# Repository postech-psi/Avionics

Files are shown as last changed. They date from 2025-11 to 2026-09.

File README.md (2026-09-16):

# PSI Avionics

Flight software and ground station for the POSTECH PSI rocket avionics system.
The flight computer runs on an Arduino Portenta H7. Its M7 core reads the
sensors and controls parachute deployment; the M4 core records flight data to
SD and sends telemetry over XBee.

The ground station brings live telemetry into one view: 3D attitude and flight
path, sensor plots, flight statistics, and sensor status. It records each
connection and replays saved logs for flight review, with offline satellite
maps for use at the launch site.

## Repository layout

```text
flight-computer/
  src/m7/       Flight control and state estimation
  src/m4/       SD logging and XBee telemetry
  src/shared/   Telemetry and inter-core packet definitions
  lib/          Firmware libraries, including the UKF and modified BMP3XX driver
  docs/         IMU configuration
  legacy/       Original single-core firmware
ground-station/
  Groundstation.py         Ground station with map and log replay
  README.md               Ground station setup and operating guide
  fetch_basemap.py         Offline basemap downloader
  logs/                   Recorded flight data
```

## Build the firmware

Install PlatformIO through VS Code or Python, then build both cores from the
repository root:

```bash
python -m pip install platformio
pio run -d flight-computer
```

The project uses ST STM32 19.5.0 and Arduino Mbed 4.5.0. The sensor libraries
are included in the repository. Keep the local BMP3XX driver: the firmware
uses its normal-mode and nonblocking-read functions.

Read the [firmware guide](flight-computer/README.md) before uploading. It covers
wiring, sensor settings, startup calibration, and deployment behavior. Upload
M4 first, then M7:

```bash
pio run -d flight-computer -e portenta_h7_m4 -t upload
pio run -d flight-computer -e portenta_h7_m7 -t upload
```

## Run the ground station

From the repository root:

```bash
cd ground-station
python -m pip install -r requirements.txt
python Groundstation.py
```

Select the XBee serial port and click **CONNECT**. The app uses **115200 baud**
and starts recording automatically. Check the **REC** indicator; recordings
are saved as a telemetry CSV and an event TXT file under `ground-station/logs/`.
**STOP LOG** ends recording, and **START LOG** opens another session.

Use **PLOT CONTROL** to select graphs and **FOLLOW** to keep the flight path
in view. **OPEN LOG** replays a ground station CSV or a flight-computer SD CSV
after disconnecting the serial port. Replay supports pause, speed selection,
and seeking through the flight.

The [ground station guide](ground-station/README.md) explains the displays,
sensor status, recording formats, and replay controls.

The map opens as a grid when no basemap is installed. Download imagery before
going to the launch site:

```bash
python fetch_basemap.py site1  # 고흥만 항공센터
python fetch_basemap.py site2  # POSTECH 풍동동
```

For another location:

```bash
python fetch_basemap.py mysite --lat 34.61 --lon 127.21 --label "예비 발사장"
```

Maps are saved in `basemaps/` and work offline after download. Restart the app
after downloading and select the site from **MAP**. Downloaded maps and the
tile cache are excluded from Git.

## Legacy firmware

The original single-core project is kept in
[`flight-computer/legacy/`](flight-computer/legacy/README.md), with its original
source, libraries, and build configuration. It builds separately from the
current firmware and uses an older telemetry format.

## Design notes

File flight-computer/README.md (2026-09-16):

# PSI 비행 컴퓨터

Arduino Portenta H7용 로켓 비행 펌웨어다. M7은 센서 수집, 상태 추정,
발사·전개·착지 판단과 서보 제어를 담당한다. M4는 M7에서 받은 데이터를
SD카드에 기록하고 XBee로 지상국에 보낸다.

| 코어 | 소스 | 실행 주기 |
|---|---|---|
| M7 | `src/m7/main_m7.cpp` | 비행 루프 100Hz, UKF는 새 기압 샘플마다 약 50Hz |
| M4 | `src/m4/main_m4.cpp` | 수신 데이터 SD 기록, XBee 송신 25Hz |

기존 단일코어 펌웨어는 [`legacy/`](legacy/README.md)에 있다.
현재 프로젝트를 빌드할 때는 포함되지 않는다.

## 하드웨어 연결

| 장치 | 연결 | 펌웨어가 사용하는 설정 |
|---|---|---|
| EBIMU-9DOFV6 | UART PJ_8 / PJ_9 | 230400 baud, 12필드 ASCII, 100Hz |
| NEO-M9N | UART PG_14 / PG_9 | 38400 baud, UBX-NAV-POSLLH, 25Hz |
| BMP390 | Wire2, I2C 주소 `0x76` | 기압 ×8, 온도 오버샘플링 없음, IIR 계수 3, 50Hz |
| 낙하산 서보 | D2 | 0° 개방, 120° 잠금 |
| XBee | Serial1 | 115200 baud, M4에서 사용 |
| microSD | Breakout 보드 SDMMC 슬롯 | M4에서 사용 |

IMU와 GNSS의 출력 설정은 센서에 미리 저장되어 있어야 한다. 비행 펌웨어는
부팅 때 출력 형식을 설정하지 않는다. IMU 설정과 복구 방법은
[IMU 설정 문서](docs/IMU_EBIMU_CONFIG.md)를 참고한다.

기울기 판정은 기수가 위를 향할 때 `cos(roll) × cos(pitch)`가 약 −1인
장착 방향을 전제로 한다. 센서나 서보 장착을 바꾸면 각도와 개방 방향을
다시 확인해야 한다.

## 1. 빌드

이 문서의 명령은 `flight-computer/`에서 실행한다. PlatformIO가 필요하며,
플랫폼과 프레임워크 버전은 `platformio.ini`에 고정되어 있다.

```bash
pio run
```

결과물은 `.pio/build/portenta_h7_m7/firmware.bin`과
`.pio/build/portenta_h7_m4/firmware.bin`이다. 라이브러리는 `lib/`에 포함되어
있다. BMP3XX 드라이버에는 `setupNormalMode()`와 `readNonBlocking()`이
추가되어 있으므로 원본 라이브러리로 교체하면 현재 코드를 빌드할 수 없다.

## 2. 업로드

**M4를 먼저 올리고 M7을 나중에 올린다.** M7의 `RPC.begin()`이 M4를 부팅한다.

```bash
pio run -e portenta_h7_m4 -t upload
pio run -e portenta_h7_m7 -t upload
```

자동 업로드가 포트 오류로 실패하면 RESET 버튼을 두 번 눌러 DFU 모드로
진입한 뒤 `dfu-util`로 업로드할 수 있다. 아래 주소는 현재 보드 설정의
플래시 시작 주소다.

```bash
dfu-util -l
dfu-util -d 0x2341:0x035b -a 0 -s 0x08100000 -D .pio/build/portenta_h7_m4/firmware.bin
dfu-util -d 0x2341:0x035b -a 0 -s 0x08040000:leave -D .pio/build/portenta_h7_m7/firmware.bin
```

부팅 중 서보가 움직인다. 장착된 분리 장치가 작동할 수 있으므로 전원을
넣기 전에 시험 구성을 확인한다.

## 3. 부팅과 캘리브레이션

```bash
pio device monitor -b 115200
```

M7은 RPC 연결과 송신 스레드를 시작한 뒤 센서를 확인한다. 기압계 초기화는
최대 10초 동안 재시도하고, IMU와 GNSS는 2초 동안 수신 상태를 확인한다.
이후 다음 순서로 준비한다.

1. 서보를 잠금 → 개방 → 잠금 순서로 움직인다.
2. IMU가 응답하면 자이로 영점 보정과 위치 초기화를 수행한다. 자이로 보정
   중에는 정지 상태를 유지한다. 이어지는 15초 자기계 보정 구간에는 로그
   안내에 따라 센서를 여러 방향으로 회전한다.
3. 기압계가 응답하면 6초 동안 기준기압을 측정한다. 이때 기체를 정지시킨다.
4. 미션 시계를 시작하고 `PRELAUNCH`로 전환한다.

기준기압은 정상 모드 설정 성공, 유효 샘플 200개 이상, 거부 샘플 20개 이하,
최대·최소 차이 0.5hPa 이하일 때 사용할 수 있다. 실패하면 고도 발사 판단과
속도 전개 경로가 비활성화된다.

RPC 초기화나 송신 스레드 시작에 실패하면 빨간 LED를 점멸하며 부팅을
멈춘다. IMU와 기준기압을 모두 사용할 수 없으면 발사를 감지할 수 없다.
14초 강제 전개 타이머도 발사가 감지된 뒤에만 시작한다.

## 4. 텔레메트리

지상국 실행 방법은 [저장소 README](../README.md#run-the-ground-station)에 있다.
XBee 프레임은 총 92바이트이며, payload는 little-endian이다.

```text
0x7E | state (1 byte) | float32 × 22 | health (1 byte) | 0x0A
```

float 필드 순서는 `time`, `lat`, `lon`, `euler[3]`, `accel[3]`, `gyro[3]`,
`pos[3]`, `altitude`, `pressure`, `kalman[4]`, `gnssAlt`다.
시간은 미션 시작 후 ms, 기압은 hPa, 고도는 m다. `kalman[4]`에는 추정 고도,
수직속도, 예측 정점고도, 회귀 적합도 R²가 들어간다.

상태 바이트는 `0xBA` PRELAUNCH, `0xBB` LAUNCH, `0xBC` DEPLOY,
`0xBD` LANDED다. 지상국은 마지막 상태를 GROUND로 표시한다.
텍스트 로그는 `0xAA` 접두 바이트와 CRLF로 구분한다.

| Health 비트 | 의미 |
|---|---|
| `0x01` | IMU 데이터가 30ms 이내 |
| `0x02` | 기압 데이터가 60ms 이내 |
| `0x04` | IMU가 500ms 내에 응답 |
| `0x08` | 기압계가 500ms 내에 응답 |
| `0x10` | 유효 GNSS 프레임을 1초 내에 수신 |
| `0x20` | 기준기압 품질검사 통과 |
| `0x40` | 속도 전개 경로가 영구 차단되지 않음 |
| `0x80` | 현재 속도 전개 입력을 사용할 수 있음 |

`0x80`은 발사 여부나 5초 전개 잠금을 나타내는 비트가 아니다.
GNSS 응답 비트도 위치 fix를 보장하지 않는다.

## 5. SD 기록

M4는 부팅마다 사용하지 않은 번호를 찾아 `flight_NNN.csv`와
`flight_NNN.txt`를 만든다. CSV에는 수신한 텔레메트리를, TXT에는 센서 초기화,
캘리브레이션과 상태 전환 메시지를 기록한다. 000부터 999까지 모두 사용하면
새 기록을 시작하지 않는다.

CSV의 `time_ms`와 M7 텍스트 로그의 `[ms]`는 같은 미션 시계를 사용한다.
부팅 로그는 미션 시계가 시작되기 전의 시간을 사용하며,
`[ZERO] mission clock start`가 경계를 표시한다. M4 자체 메시지는 `[M4 ms]`로
구분한다.

마지막 `note` 열은 health 비트를 풀어 쓴 값이다. 여러 상태는 `|`로 이어진다.

| Note | 의미 |
|---|---|
| `ok` | 모든 health 비트가 설정됨 |
| `imu_stale`, `baro_stale` | 센서는 응답하지만 데이터가 제어 유효기간을 넘김 |
| `imu_dead`, `baro_dead`, `gnss_dead` | 센서 응답 시간 초과 |
| `no_baro_ref` | 유효한 기준기압 없음 |
| `vz_settle` | 속도 경로는 유지되지만 현재 입력을 사용할 수 없음 |
| `vz_off` | 속도 전개 경로 차단 |

센서가 끊겨도 마지막 측정값은 남아 있을 수 있다. 지상국의 SD 로그 재생은
측정값 존재 여부 대신 이 note를 읽어 상태를 표시한다.

SD 쓰기는 별도 스레드에서 수행하고 200ms 간격으로 flush와 fsync를 시도한다.
쓰기 오류가 연속 세 번 발생하면 기록을 중단하고 XBee로 알린다. 버퍼가 차면
데이터가 유실될 수 있고, 실패한 쓰기를 재시도하는 과정에서 CSV 행이 중복될
수 있다. LANDED 전환 때 출력되는 비행 요약의 drop 카운터와 시간을 함께 확인한다.

## 6. 동작 원리

### 6.1 실행 구조

M7 루프는 GNSS·IMU·기압 수집, UKF 갱신, 센서 상태 갱신, 비행 판단,
텔레메트리 큐 적재 순서로 실행된다. 10ms 마감 시각을 놓치면 지나간 주기를
건너뛴다. RPC 쓰기와 USB 로그 출력은 별도 송신 스레드가 담당한다.

### 6.2 데이터 흐름

UKF는 IMU의 전역 Z축 가속도와 기압고도를 입력으로 사용한다. GNSS 위치와
해수면고도, IMU 적분 위치는 기록·회수용이며 비행 판단에는 사용하지 않는다.
기압고도는 부팅 때 정한 기준기압에 대한 상대 높이다.

### 6.3 센서 입력

IMU는 `*roll,pitch,yaw,gx,gy,gz,ax,ay,az,dx,dy,dz` 형식의 12필드만 받는다.
숫자 형식, 유한값, 자세·각속도·가속도 범위를 확인한 뒤 갱신한다.

기압은 300–1250hPa 범위를 확인한다. 직전 유효 샘플과 200ms 이내라면
고도 변화율도 검사한다. 새 샘플이 없으면 기존 값으로 UKF를 다시 계산하지 않는다.

GNSS는 체크섬이 맞는 UBX-NAV-POSLLH 프레임을 받는다. 수평 정확도가
100m 이내이고 위도·경도 범위가 유효할 때 위치를 갱신한다. POSLLH에는
fix 유효 플래그가 없으므로 이 조건만으로 항법용 위치를 보장할 수는 없다.

### 6.4 데이터 유효기간

제어 입력 유효기간과 센서 응답 시간 초과는 별개다. IMU 30ms, 기압 60ms를
넘은 값은 해당 제어 투표에 사용하지 않는다. 센서 응답 여부는 더 긴
IMU·기압 500ms, GNSS 1000ms 기준으로 판단한다.

### 6.5 상태 추정

UKF의 시간 간격은 0.02초로 고정되어 있다. IMU의 중력 제거 가속도(g)를
m/s²로 바꾸고 중력항을 더해 필터에 넣는다. 출력 수직속도는 위쪽이 양수다.

기압 간격 100개의 평균이 17.5–22.5ms에 들어오면 속도 경로의 주기 조건을
통과한다. 이후에도 50개 간격마다 평균을 확인한다. 35ms보다 긴 공백이나
최근 네 정상 간격의 합이 70–90ms 범위를 벗어나면 속도 입력을 500ms 동안 막는다.

### 6.6 투표 창

발사와 전개는 한 번의 측정으로 판단하지 않는다. 각 조건이 최근 N회 중
몇 회 참이었는지 센다. 모든 투표는 100Hz 루프에서 갱신되므로 루프가
지연되면 실제 판단 시간도 길어진다.

### 6.7 비행 상태 전환

PRELAUNCH에서는 수직 가속도 절댓값이 2g를 넘는 표가 20회 중 12회이거나,
최근 두 기압 샘플의 평균 고도가 10m를 넘는 표가 40회 중 24회이면 LAUNCH로
전환한다. 고도 경로에는 유효한 기준기압이 필요하다.

발사 감지 뒤 **5초 동안 모든 전개 경로를 잠근다.** 잠금이 풀리면 아래
순서로 판단한다. 14초 타이머는 센서 경로와 별도로 평가한다.

| 경로 | 조건 |
|---|---|
| 속도 | 사용 가능한 추정 수직속도가 −7m/s 미만인 표가 12회 중 7회 |
| 기울기 백업 | 속도 경로가 비활성이고 IMU가 유효할 때, `cos(roll) × cos(pitch) > 0.70711`인 표가 25회 중 15회 |
| 강제 타이머 | 발사 감지 후 14초 초과 |

속도 경로가 선택되어 있으면 기울기 표는 쌓이지 않는다. 다만 잠금 해제 후
속도 입력을 **1000ms 연속 사용할 수 없으면** 속도 경로를 영구 차단하여
기울기 백업을 허용한다. 중간에 입력이 사용 가능해지면 이 연속 시간은
초기화된다. 짧은 공백은 복구를 기다리고, 지속적인 저하는 백업으로 넘긴다.

DEPLOY에 들어가면 서보를 먼저 연다. 1초 동안 개방한 뒤 착지하지 않았으면
500ms 잠갔다 다시 여는 동작을 반복한다. 잠금 중 루프가 지연될 경우를 위해
600ms 후 개방하는 타이머도 설정한다.

착지는 자이로 벡터 크기 5dps 이하, 가속도 벡터 크기 0.2g 이하인 정적
상태가 최근 2500회 중 1500회 누적될 때 판단한다. 기준 고도에서 2m를 벗어나면
투표를 초기화한다. LANDED 전환은 서보가 열린 상태에서만 수행한다.

### 6.8 센서 고장 시 동작

비행 중 기압 공백이 200ms를 넘거나 IMU 응답이 끊기면 속도 경로를 영구
차단한다. IMU가 복구되어도 속도 경로는 다시 켜지지 않고 기울기 백업만
사용할 수 있다. IMU도 사용할 수 없으면 강제 타이머만 남는다.

착지 판단에서는 IMU가 응답하지 않으면 움직임이 없는 것으로 취급한다.
기압계까지 끊기면 고도도 고정되므로, 이 경우의 LANDED 표시는 실제 착지를
확인한 결과가 아니다. 서보 재시도 종료 여부를 해석할 때 구분해야 한다.

### 6.9 설정 위치

주기, 임계값, 투표 수와 시간 제한은 `main_m7.cpp`의 `[4] Parameters`에 있다.
서보 각도는 `[2] Sensor Mapping`, 송신 간격은 M4의 `TELEM_DECIMATE`에서 정한다.
현재 값은 4로, 수신 데이터 네 개마다 한 프레임을 XBee로 보낸다.

### 6.10 코어 간 통신

IPC 프레임은 시작 바이트 `0xA5`, 타입, 2바이트 길이, payload, XOR 체크섬으로
구성된다. M4는 체크섬이 맞는 프레임만 처리한다. M7 송신 큐가 차면
비행 루프를 대기시키지 않고 프레임을 버린 뒤 누락 횟수를 기록한다.

### 6.11 유지보수

비행 루프에 RPC·SD·USB 출력을 직접 추가하지 않는다. 센서 수집 경로에도
시간이 제한되지 않은 대기가 들어가지 않도록 확인한다. 강제 전개 타이머는
루프가 실행되는 동안에만 평가된다.

패킷을 바꿀 때는 `src/shared/telemetry_frame.h`와 지상국의 수신 형식을 함께
수정한다. 서보 동작, 센서 설정, 전개 임계값 변경은 실제 장착 상태에서
확인해야 한다. 빌드 성공만으로 장치 동작이나 비행 적합성을 판단하지 않는다.

## 문제 확인

| 증상 또는 로그 | 확인할 항목 |
|---|---|
| 빨간 LED 반복 점멸 | M4 펌웨어와 업로드 순서, RPC 초기화 오류 |
| `IMU ... format invalid` | 12필드 출력 설정과 230400 baud |
| `GNSS no response` | 38400 baud, UART 출력이 UBX-POSLLH인지 확인 |
| `Baro reference quality fail` | 부팅 중 기체 움직임, 압력 변동, 샘플 수 |
| `vz deploy path disabled` | 함께 출력된 차단 사유와 센서 상태 |
| `SD disabled` | 카드 장착·파일시스템·남은 세션 번호 |
| `SD write failed` | 카드 쓰기 오류. 해당 부팅의 SD 기록은 중단됨 |
| `RPC link` 또는 `deadline skips` | 송신 누락과 비행 루프 실행시간 |

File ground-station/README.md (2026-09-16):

# PSI Ground Station

The ground station receives XBee telemetry from the Portenta H7 flight computer.
It shows the rocket's attitude and flight path alongside sensor plots, flight
statistics, and system messages. The same displays can replay recorded flights
without a serial connection.

## Start the app

Run these commands from the repository root:

```bash
cd ground-station
python -m pip install -r requirements.txt
python Groundstation.py
```

Keep the two STL models and `PSI Logo.png` beside the Python script. The 3D
views load these local assets and use OpenGL.

## Connect and record

1. Connect the receiving XBee to the computer over USB.
2. Click **REFRESH**, select its serial port, and click **CONNECT**. The serial
   speed is fixed at 115200 baud.
3. Check the connection status, incoming telemetry, and **REC** indicator.
   Recording starts automatically when the connection opens.
4. Click **DISCONNECT** when finished. This also closes the recording files.

**STOP LOG** closes the current recording while leaving the serial connection
open. **START LOG** opens a new recording. Each session creates two files in
`ground-station/logs/`:

| File | Contents |
|---|---|
| `log_YYYYMMDD_HHMMSS.csv` | Received telemetry, including timestamps and health flags |
| `log_YYYYMMDD_HHMMSS.txt` | Text events and system messages |

The ground station records what arrives over the radio. The flight computer's
SD recording is a separate source and can contain samples missed by the radio
link. Keep both when reviewing a flight.

## Read the display

| Panel | What it shows |
|---|---|
| **3D ATTITUDE** | Rocket orientation from the IMU |
| **3D FLIGHT PATH** | Position history over a grid or a saved satellite map |
| **PLOT CONTROL · REPLAY** | Graph selection, map controls, and log playback |
| **FLIGHT STATS** | Maximum altitude, ascent and descent rates, acceleration, and deployment and ground times |
| **SENSOR HEALTH** | Sensor response, data freshness, reference pressure, and velocity-path status |
| **TELEMETRY / SYSTEM LOG** | Received values and firmware messages |

The available graphs cover acceleration, angular rate, altitude, vertical
velocity, and predicted apogee. Use the checkboxes to choose the graphs and
individual curves. Double-click a graph after manually panning or zooming to
return to its automatic view.

**FOLLOW** fits the camera to the flight path. Moving the camera manually turns
it off; select it again to resume following. **TOP** switches to a north-up
overhead view. The toolbar **RESET** clears the displayed history and statistics
while the connection and recording continue.

Deployment and ground times in **FLIGHT STATS** are measured from the received
LAUNCH transition. If that transition was missed, the panel shows
`no launch ref`. Predicted apogee is the current onboard estimate; the maximum
altitude statistic is the highest received Kalman altitude.

## Sensor status

IMU and barometer status distinguish **FRESH**, **STALE**, and **DEAD**. A sensor
may still respond while its latest measurement is too old for flight control.
GNSS **ALIVE** means the firmware received an accepted position frame; it does
not guarantee a valid navigation fix.

The velocity path shows **USABLE**, **SETTLING**, or **DISABLED**. These describe
the firmware's velocity input, not whether deployment is armed. The
[firmware guide](../flight-computer/README.md#4-텔레메트리) defines the health
bits and timing thresholds.

## Replay a flight

Disconnect the serial port, then click **OPEN LOG** and choose a telemetry file.
Playback starts immediately. Use the pause/play button, select a speed from
1× to 50×, or drag the slider to inspect a particular point in the flight.
Seeking rebuilds the plotted history and flight statistics up to that point.

The reader accepts ground station CSV recordings, flight-computer SD CSV files
such as `flight_000.csv`, and older TXT logs containing telemetry rows. The
current event-only TXT files do not contain frames for replay; open the paired
CSV instead.

For current SD CSV files, sensor status comes from the `note` column. Older
files without encoded health information use a limited estimate based on the
stored values, so their status display is less complete.

## Prepare offline maps

Download maps while internet access is available. From `ground-station/`:

```bash
python fetch_basemap.py site1  # 고흥만 항공센터
python fetch_basemap.py site2  # POSTECH 풍동동
```

For another location, supply a name and coordinates:

```bash
python fetch_basemap.py mysite --lat 34.61 --lon 127.21 --label "예비 발사장"
```

The downloader creates a PNG and matching JSON metadata in `basemaps/`. Keep
each pair together when copying maps to another computer. Restart the ground
station after downloading, then choose the site from **MAP**. The app reads
these files locally during a flight. Without a downloaded map, it shows a grid.

Downloaded maps and `tilecache/` are excluded from Git. Run
`python fetch_basemap.py --help` for coverage and zoom options.

## Common problems

| Symptom | What to check |
|---|---|
| Serial port is missing | USB connection and adapter driver; click **REFRESH** after reconnecting |
| Port cannot be opened | Close other serial monitors using the same port |
| Connected, but no telemetry | XBee pairing, receiver serial settings, and whether both flight-computer cores are running |
| 3D view fails to open | Graphics driver, OpenGL support, and the STL files beside the script |
| Map list is empty | Download a basemap and restart the app |
| Replay finds no telemetry | Open the CSV rather than an event-only TXT file |

The live receiver expects the current dual-core firmware's packet format.
See the [legacy firmware guide](../flight-computer/legacy/README.md) when
working with the archived single-core project.

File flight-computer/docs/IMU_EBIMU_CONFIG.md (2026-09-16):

# EBIMU-9DOFV6 설정

현재 M7 펌웨어는 230400 baud에서 다음 12필드 ASCII 출력을 받는다.

```text
*roll,pitch,yaw,gx,gy,gz,ax,ay,az,dx,dy,dz
```

출력 설정은 IMU에 저장한다. 비행 펌웨어는 부팅 때 이 형식을 다시 설정하지
않으므로 센서를 교체하거나 초기화한 뒤에는 설정을 확인해야 한다.

## 출력과 측정 범위

| 명령 | 설정 |
|---|---|
| `<sof1>` | Euler 자세각, deg |
| `<sog1>` | 각속도 출력, dps |
| `<soa3>` | 중력을 제거한 전역 좌표계 가속도, g |
| `<som0>` | 지자기 출력 끄기 |
| `<sod2>` | 전역 좌표계 적분 위치 출력, m |
| `<sor10>` | 출력 주기 10ms, 100Hz |
| `<sb6>` | UART 230400 baud |
| `<ssa4>` | 가속도 측정 범위 ±16g |
| `<ssg5>` | 각속도 측정 범위 ±2000dps |

설정 후 한 줄에 숫자 12개가 들어오는지 확인한다. 온도 등 다른 필드를
추가하면 현재 파서가 해당 줄을 거부한다.

`soa3`에서는 정지했을 때 가속도 세 축이 모두 0에 가까워야 한다.
발사 판단에 쓰는 Z축 가속도는 중력이 제거된 전역 수직 가속도다.
`sod2`의 적분 위치는 시간이 지나면 오차가 누적되며, 비행 판단에는 쓰지 않는다.

## 설정 명령 보내기

아래 스케치를 M7에 임시로 업로드하면 USB 시리얼 터미널에서 IMU와 직접
통신할 수 있다. 터미널은 115200 baud로 연다. `IMU.begin()`의 속도는
센서에 현재 저장된 속도와 맞아야 한다. IMU 속도를 바꾼 뒤에는 이 값도
바꾸어 다시 업로드한다.

```cpp
#include <Arduino.h>

UART IMU(PJ_8, PJ_9, NC, NC);

void setup() {
    Serial.begin(115200);
    IMU.begin(230400);
}

void loop() {
    while (Serial.available()) IMU.write((uint8_t)Serial.read());
    while (IMU.available()) Serial.write((uint8_t)IMU.read());
}
```

작업이 끝나면 [비행 펌웨어](../README.md#2-업로드)를 다시 업로드한다.

## 확인과 보정

| 명령 | 용도 |
|---|---|
| `<cfg>` | 저장 설정 확인. 확인 후 `>`를 보내 스트림 재개 |
| `<ver>` | 센서 펌웨어 버전 확인 |
| `<posz>` | 누적 속도·거리 초기화 |
| `<cg>` | 정지 상태에서 자이로 보정 |
| `<cmf>` | 센서를 회전하며 자기계 보정, `>`로 종료 |
| `<caf>` | 가속도 정밀 보정 |
| `<lf>` | 공장 초기화. 이후 출력 형식과 통신 속도를 다시 설정해야 함 |

비행 펌웨어의 부팅 절차에도 자이로 보정, 위치 초기화와 자기계 보정이
포함되어 있다. 부팅 로그에 맞춰 정지와 회전 구간을 구분한다.

과거 로그를 해석할 때는 당시 출력 설정도 확인한다. 이전 `som1` 설정의
로그에서는 `pos` 열에 지자기 값(µT)이 저장되었고, 현재 `sod2` 설정에서는
적분 위치(m)가 저장된다.

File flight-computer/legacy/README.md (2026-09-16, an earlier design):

# Legacy firmware

This is the original single-core Portenta H7 firmware from
[commit 6df6d0e](https://github.com/postech-psi/Avionics/tree/6df6d0e4ed5a65a6c21af55266a050eb3e845649).
The source, libraries, and PlatformIO configuration are kept as they were.

Build it from the repository root:

```bash
pio run -d flight-computer/legacy -e portenta_h7_m7
```

This is a separate PlatformIO project. Building `flight-computer/` does not
include the legacy sources or libraries. Its platform dependency remains
unpinned, as in the original configuration.

The current ground station expects a newer telemetry packet. To use the old
firmware with its original receiver, take the ground-station code from the
same commit or the `legacy-single-core-2026-09-17` tag.

The `legacy-pre-migration-2026-09-17` tag preserves the working tree before
the firmware replacement, including newer ground-station files and flight
logs. It is an archive of that working state; the firmware and receiver in
that tag use different packet formats.

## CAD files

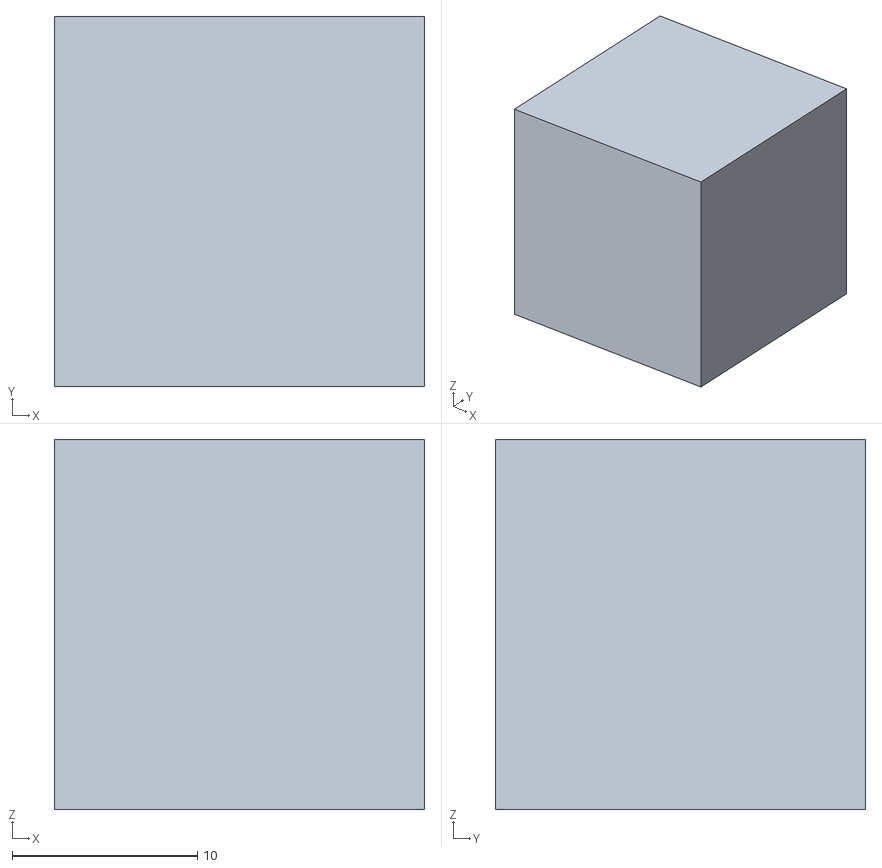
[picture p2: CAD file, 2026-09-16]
ground-station/current_pos_box.stl
20.0 x 20.0 x 20.0

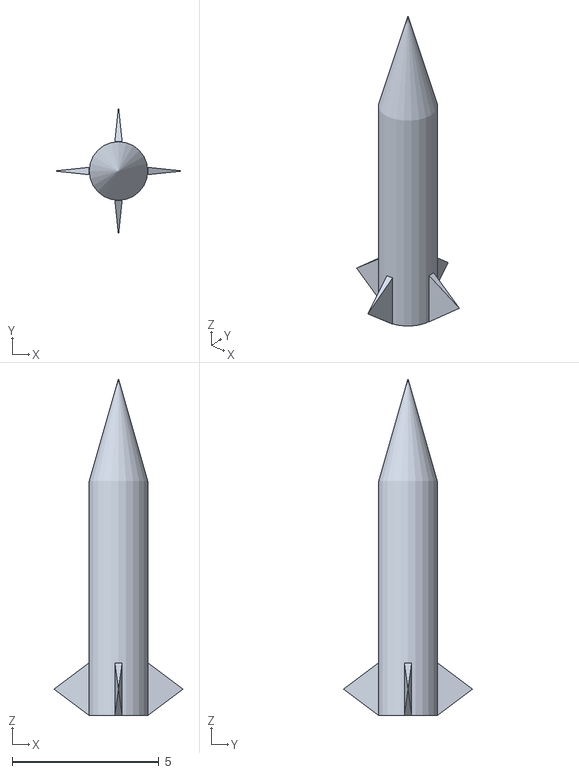
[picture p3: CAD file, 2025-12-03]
ground-station/PSLV_I.V_simplemodel.stl
4.40 x 4.40 x 11.5

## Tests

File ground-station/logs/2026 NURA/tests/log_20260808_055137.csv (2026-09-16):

wall | t | state | lat | lon | gnss_alt | roll | pitch | yaw | ax | ay | az | gx | gy | gz | px | py | pz | baro_alt | pressure | kf_alt | kf_vz | apogee | r2 | health
05:52:28.937 | 0.033 | PRELAUNCH | 36.0213890 | 129.3214417 | 209.42 | 179.310 | 4.350 | -104.020 | 0.0060 | -0.0490 | 0.0100 | -0.710 | 3.520 | -2.520 | -17.177 | -18.079 | -0.652 | -0.063 | 1002.681 | -0.065 | -0.619 | 2.541 | nan | 127
05:52:28.977 | 0.073 | PRELAUNCH | 36.0212364 | 129.3213806 | 102.88 | 179.320 | 4.390 | -104.070 | 0.0040 | -0.0560 | 0.0060 | -0.480 | 4.060 | -0.880 | -17.203 | -18.246 | -0.651 | -0.048 | 1002.680 | -0.054 | -0.066 | nan | nan | 127
05:52:29.020 | 0.112 | PRELAUNCH | 36.0212364 | 129.3213806 | 102.83 | 179.330 | 4.430 | -104.130 | 0.0010 | -0.0600 | 0.0020 | -0.590 | 3.880 | -1.790 | -17.235 | -18.457 | -0.650 | -0.069 | 1002.682 | -0.080 | -0.312 | 0.858 | nan | 127
05:52:29.061 | 0.153 | PRELAUNCH | 36.0212364 | 129.3213806 | 102.74 | 179.340 | 4.440 | -104.180 | -0.0010 | -0.0630 | 0.0000 | -0.410 | 3.450 | -1.180 | -17.260 | -18.627 | -0.649 | -0.074 | 1002.682 | -0.086 | -0.246 | nan | nan | 127
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

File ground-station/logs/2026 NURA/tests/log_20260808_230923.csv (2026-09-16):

wall | t | state | lat | lon | gnss_alt | roll | pitch | yaw | ax | ay | az | gx | gy | gz | px | py | pz | baro_alt | pressure | kf_alt | kf_vz | apogee | r2 | health
23:09:55.487 | 0.033 | PRELAUNCH | 36.0154533 | 129.3218994 | 32.60 | -170.390 | -9.460 | -151.480 | -0.0430 | -0.0540 | 0.0100 | -0.860 | -0.070 | 0.990 | -8.738 | -7.282 | 0.253 | -0.021 | 1006.565 | -0.017 | -0.416 | 1.186 | nan | 127
23:09:55.535 | 0.073 | PRELAUNCH | 36.0154266 | 129.3219452 | 41.22 | -170.330 | -9.590 | -151.480 | -0.0280 | -0.0540 | 0.0180 | 0.000 | 0.000 | 0.000 | -8.772 | -7.322 | 0.256 | 0.003 | 1006.562 | -0.009 | -0.014 | nan | nan | 127
23:09:55.569 | 0.112 | PRELAUNCH | 36.0154228 | 129.3219452 | 41.26 | -170.230 | -9.700 | -151.510 | -0.0280 | -0.0500 | 0.0160 | 0.370 | 0.980 | -0.120 | -8.814 | -7.374 | 0.260 | 0.000 | 1006.563 | 0.013 | 0.223 | nan | nan | 127
23:09:55.623 | 0.153 | PRELAUNCH | 36.0154228 | 129.3219452 | 41.27 | -170.160 | -9.790 | -151.490 | -0.0440 | -0.0470 | 0.0050 | 0.550 | 0.730 | 0.680 | -8.848 | -7.416 | 0.263 | 0.005 | 1006.562 | 0.005 | 0.071 | nan | nan | 127
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

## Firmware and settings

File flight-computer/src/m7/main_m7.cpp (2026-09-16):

//~~~~~~~~~~~~~~~~~~~~~~~~~~~~~~~~~~~~~~~~~~~~~~~~~~~~~~~~~~~~~~~~~~~~~~~~~~~//
//~~~~~~~ main_m7.cpp - Portenta H7 (STM32H747) dual-core avionics : M7 ~~~~~//
//~~~~~~~~~~~~~~~~~~~~~~~~~~~~~~~~~~~~~~~~~~~~~~~~~~~~~~~~~~~~~~~~~~~~~~~~~~~//
// All real-time flight control, single-thread superloop at a fixed 100Hz:
//   GNSS/IMU/Baro -> UKF -> decision FSM -> parachute servo, then the full
//   frame to M4 over RPC. XBEE(Serial1) and SD belong to M4 - never touched here.
//
// EVERYTHING about this file is documented in README section 6:
//   6.1 loop structure   6.3 sensor validity   6.4 freshness grades
//   6.5 UKF at 50Hz      6.6 vote windows      6.7 state transitions
//   6.9 parameter table  6.11 lines you must not delete
// Comments below are limited to "// !" markers on those must-not-delete lines.
// Build & upload (M4 FIRST, then M7) : README 1-2.
//
// [File map] - the [N] tags match the section banners in this file
//   [1] Data Structure      [2] Sensor Mapping     [3] Flight State
//   [4] Parameters          [5] State & Freshness  [6] IPC Transmit
//   [7] Logging             [8] Parsing            [9] Sensor Health
//  [10] VoteWin            [11] Decision          [12] Startup Checks
//  [13] Sensor Check       [14] Setup             [15] Main Loop
//~~~~~~~~~~~~~~~~~~~~~~~~~~~~~~~~~~~~~~~~~~~~~~~~~~~~~~~~~~~~~~~~~~~~~~~~~~~//
#include <Arduino.h>
#include <Servo.h>
#include <Wire.h>
#include <Adafruit_BMP3XX.h>
#include <Adafruit_Sensor.h>
#include "mbed.h"
#include "rtos.h"
#include <chrono>
#include <RPC.h>
#include "ukf.h"
#include "rtwtypes.h"
#include "../parsers.h"
#include "../shared/telemetry_frame.h"
#include "../shared/ipc_protocol.h"

using namespace mbed;
using namespace rtos;
using namespace std::chrono;
kf Kalmanfilter;

//~~~~~~~~~~~~~~~~~~~~~~~~~~~~~~~~~~~~~~~~~~~~~~~~~~~~~~~~~~~~~~~//
//~~~~~~~~~~~~~~~~ [1] Data Structure (M7 local) ~~~~~~~~~~~~~~~~//
//~~~~~~~~~~~~~~~~~~~~~~~~~~~~~~~~~~~~~~~~~~~~~~~~~~~~~~~~~~~~~~~//
struct SensorData {
    uint8_t state = 0xBA;      // 0xBA prelaunch 0xBB launch 0xBC deploy 0xBD landed
    float time = 0.0;          // mission ms
    float lat = 0.0;
    float lon = 0.0;
    float euler[3] = {0, 0, 0};  // roll pitch yaw, deg
    float accel[3] = {0, 0, 0};  // linear accel, gravity-free, GLOBAL frame (soa3), g
    float gyro[3]  = {0, 0, 0};  // dps
    float pos[3]   = {0, 0, 0};  // integrated distance, global, m (drifts - log only)
    float altitude = 0.0;        // above pad reference, m
    float pressure = 0.0;        // hPa
    float kalman[4] = {0, 0, 0, 0};  // kf_alt, kf_vel, apogee, r2
    float gnssAlt = 0.0f;            // GNSS hMSL, m - log/recovery only,
                                     // NEVER used by any flight decision
    uint8_t health = 0;              // TLM_* flags for THIS frame
};

//~~~~~~~~~~~~~~~~~~~~~~~~~~~~~~~~~~~~~~~~~~~~~~~~~~~~~~~~~~~~~~~//
//~~~~~~~ [2] Sensor Mapping (XBEE excluded - owned by M4) ~~~~~~//
//~~~~~~~~~~~~~~~~~~~~~~~~~~~~~~~~~~~~~~~~~~~~~~~~~~~~~~~~~~~~~~~//
Adafruit_BMP3XX Barometer;                    // BMP390, I2C Wire2, 0x76
Servo           Parachute;                    // deploy servo on D2
UART            GNSS(PG_14, PG_9, NC, NC);    // NEO-M9N, UBX-POSLLH, 38400
UART            IMU(PJ_8, PJ_9, NC, NC);      // EBIMU-9DOFV6, 230400

//### Servo geometry (this airframe): 0 deg releases the chute, 120 deg locks ###
const int SERVO_OPEN_DEG  = 0;
const int SERVO_CLOSE_DEG = 120;

//### CLOSE fail-open guard: if the loop dies mid jam-retry, an ISR reopens ###
// ! armed when the retry cycle CLOSES the servo, detached on normal reopen.
//   ISR-safe: after the first write, Servo::write is bounds math + one int32
//   store consumed by the lib's own Ticker (verified in lib/Servo-master).
static mbed::Timeout servoReopenGuard;
static void servoReopenIsr() { Parachute.write(SERVO_OPEN_DEG); }

//~~~~~~~~~~~~~~~~~~~~~~~~~~~~~~~~~~~~~~~~~~~~~~~~~~~~~~~~~~~~~~~//
//~~~~~~~~~~~~~~~~~~~~~~ [3] Flight State ~~~~~~~~~~~~~~~~~~~~~~~//
//~~~~~~~~~~~~~~~~~~~~~~~~~~~~~~~~~~~~~~~~~~~~~~~~~~~~~~~~~~~~~~~//
enum class FlightState { STARTUP, PRELAUNCH, LAUNCH, DEPLOY, LANDED };
FlightState flightState = FlightState::STARTUP;

//~~~~~~~~~~~~~~~~~~~~~~~~~~~~~~~~~~~~~~~~~~~~~~~~~~~~~~~~~~~~~~~//
//~~~~~~~~~~~~~~~ [4] Parameters (README 6.9) ~~~~~~~~~~~~~~~~~~~//
//~~~~~~~~~~~~~~~~~~~~~~~~~~~~~~~~~~~~~~~~~~~~~~~~~~~~~~~~~~~~~~~//
//### Loop & flight thresholds ###
const uint32_t LOOP_PERIOD_MS       = 10;
const float   launchThreshold       = 2;
unsigned long force_deploy_time     = 14000;
const float   fallingspeedThreshold = -7;
const float   TILT_COS_LIMIT        = 0.70711f;
const float   launchAltThreshold    = 10.0f;

//### Vote windows: fire when >= need of the last N votes are true ###
// need = 60% of N (2026-08-04). vz is 7/12 = 58.3% - 12*0.6 = 7.2 is not an
// integer and 7 lands far closer to 60% than 8 (66.7%).
const uint16_t VOTE_ACCEL_N  = 20,   VOTE_ACCEL_NEED  = 12;    // 60%,   ~120ms
const uint16_t VOTE_ALT_N    = 40,   VOTE_ALT_NEED    = 24;    // 60%,   ~240ms
const uint16_t VOTE_VZ_N     = 12,   VOTE_VZ_NEED     = 7;     // 58.3%,  ~70ms
const uint16_t VOTE_TILT_N   = 25,   VOTE_TILT_NEED   = 15;    // 60%,   ~150ms
const uint16_t VOTE_STATIC_N = 2500, VOTE_STATIC_NEED = 1500;  // 60%,    ~15s
const uint32_t DEPLOY_LOCKOUT_MS    = 5000;   // launch+5s: ALL deploy paths locked

//### Static landing (the only landing path) ###
const float    STATIC_GYRO_DPS      = 5.0f;
const float    STATIC_ACCEL_G       = 0.2f;
const float    STATIC_ALT_BAND_M    = 2.0f;

//### Barometer plausibility ###
const float    BARO_MAX_RATE_MPS = 680.0f;    // ~Mach 2 = 13.6m per 20ms sample
const uint32_t BARO_RATE_GAP_MS  = 200;
const uint32_t BARO_STEP_MAX_MS  = 35;        // 10ms polling x 50Hz -> 10/20/30 normal

//### Sensor health timeouts (death/recovery reporting, cal skip) ###
const uint32_t IMU_TIMEOUT_MS    = 500;
const uint32_t BARO_TIMEOUT_MS   = 500;
const uint32_t GNSS_TIMEOUT_MS   = 1000;   // 25Hz UBX stream: 25 missing = dead
const uint32_t HEALTH_LOG_MIN_MS = 2000;
const float    GNSS_HACC_MAX_M   = 100.0f;
const uint32_t BARO_BOOT_SETTLE_MS         = 3000;
const uint32_t BARO_BOOT_RETRY_WINDOW_MS   = 10000;
const uint32_t BARO_BOOT_RETRY_INTERVAL_MS = 1000;
// GNSS_HACC_MAX : POSLLH has no fix flag - a no-fix frame reads lat=lon=0 with
//                 hAcc ~4.29e6 m, so coordinates are taken only when the
//                 reported horizontal accuracy is recovery-grade (measured
//                 module config 2026-08-04). Log/recovery only, gates nothing.

//### Control freshness - SEPARATE from health, gates votes and the UKF ###
const uint32_t IMU_CTRL_FRESH_MS  = 30;
const uint32_t BARO_CTRL_FRESH_MS = 60;
const uint32_t VZ_BARO_GAP_MS     = 200;
const uint32_t VZ_SETTLE_MS       = 500;
// After the deploy lockout, sustained unusability must release the tilt backup.
// Two settle periods allow an isolated short gap to recover without a latch.
const uint32_t VZ_UNUSABLE_TIMEOUT_MS = 1000;
const float    VZ_PLAUSIBLE_MAX   = 200.0f; // |vz| beyond this = filter divergence
const uint16_t CADENCE_ARM_N       = 100;   // clean intervals to arm the vz path
const uint16_t CADENCE_BLOCK_N     = 50;    // rolling re-check block size
const float    CADENCE_MEAN_LO_MS  = 17.5f; // accepted mean band (= rolling-4
const float    CADENCE_MEAN_HI_MS  = 22.5f; //   sum 70..90). Bench: real BMP390
                                            //   ODR measured 19.42ms (+3% fast,
                                            //   oscillator tolerance) - a tight
                                            //   19.5..20.5 band killed vz on a
                                            //   HEALTHY sensor. +-12.5% scale
                                            //   error on vz is harmless; the
                                            //   guard targets 25%+ (25/30ms).
const uint32_t CADENCE_DEADLINE_MS = 10000; // arming give-up (mission ms)
const uint32_t CADENCE_FAST_SUM_LO = 70;    // last-4 clean intervals: sum 70~90
const uint32_t CADENCE_FAST_SUM_HI = 90;    //  = mean 17.5~22.5ms, checked per sample

//~~~~~~~~~~~~~~~~~~~~~~~~~~~~~~~~~~~~~~~~~~~~~~~~~~~~~~~~~~~~~~~//
//~~~~~~~~~~~~~~~~ [5] State Variables & Freshness ~~~~~~~~~~~~~~//
//~~~~~~~~~~~~~~~~~~~~~~~~~~~~~~~~~~~~~~~~~~~~~~~~~~~~~~~~~~~~~~~//
uint32_t Setup_Time    = 0;
uint32_t Setup_Time_us = 0;
float    basePressure  = 1013.0f;
float    altLaunchAvg  = 0.0f;   // mean of the 2 latest REAL baro samples
bool     baroRefValid  = false;  // ground reference passed the quality gate
bool     vzTrusted     = true;   // kalman-vz deploy path enable (one-way latch)
bool     vzCadenceOK   = false;  // measured baro interval matches the UKF's 20ms
uint32_t vzBlockUntil  = 0;      // short-gap blanking deadline
bool     altVotePendingReset = false;  // pre-launch baro gap -> wipe altitude votes
bool     vzVotePendingReset  = false;  // bad cadence -> wipe vz votes (runDecision)

uint32_t baroIvalSum   = 0;      // accepted-sample interval accounting,
uint32_t baroIvalCnt   = 0;      // reported once at PRELAUNCH

bool     imuAlive      = false;
bool     baroAlive     = false;
bool     gnssAlive     = false;
uint32_t imuLastMs     = 0;
uint32_t baroLastMs    = 0;
uint32_t gnssLastMs    = 0;
bool     rpcOK         = false;

//### Single source of truth for "fresh enough to act on" ###
static inline bool imuFreshNow(uint32_t now) {
    return imuLastMs && (now - imuLastMs) <= IMU_CTRL_FRESH_MS;
}
static inline bool baroFreshNow(uint32_t now) {
    return baroLastMs && (now - baroLastMs) <= BARO_CTRL_FRESH_MS;
}

// Every precondition of the vz deploy vote, in one place, so the flight logic
// and the logged health bit can never disagree (README 6.7).
static inline bool vzUsableNow(uint32_t now, float vz) {
    return vzTrusted && vzCadenceOK &&
           imuFreshNow(now) && baroFreshNow(now) &&
           std::isfinite(vz) && fabsf(vz) < VZ_PLAUSIBLE_MAX &&
           (int32_t)(now - vzBlockUntil) >= 0;
}

SensorData          d{};

static uint8_t sensorFlags() {
    uint32_t now = millis();
    uint8_t f = 0;
    if (imuFreshNow(now))  f |= TLM_IMU_FRESH;
    if (baroFreshNow(now)) f |= TLM_BARO_FRESH;
    if (imuAlive)          f |= TLM_IMU_ALIVE;
    if (baroAlive)         f |= TLM_BARO_ALIVE;
    if (gnssAlive)         f |= TLM_GNSS_ALIVE;
    if (baroRefValid)      f |= TLM_BARO_REF;
    if (vzTrusted)         f |= TLM_VZ_TRUSTED;
    if (vzUsableNow(now, d.kalman[1])) f |= TLM_VZ_USABLE;
    return f;
}

//~~~~~~~~~~~~~~~~~~~~~~~~~~~~~~~~~~~~~~~~~~~~~~~~~~~~~~~~~~~~~~~//
//~~~~~~ [6] IPC Transmit (ring -> BelowNormal TX thread -> RPC) ~//
//~~~~~~~~~~~~~~~~~~~~~~~~~~~~~~~~~~~~~~~~~~~~~~~~~~~~~~~~~~~~~~~//
// ! the flight loop NEVER calls the blocking RPC.write. ipcSend only pushes a
//   finished wire frame into a SPSC ring (microseconds, always returns); the
//   txThread does the blocking write. A wedged M4 therefore costs telemetry
//   frames (counted, reported) - never flight control. Same producer-priority
//   pattern as M4's hardware-proven SD writer (README 6.1 / 6.10).
const uint32_t RPC_WRITE_WARN_US = 2000;
const uint16_t TX_PAYLOAD_MAX    = 128;   // real payloads: data 90, logs <= 95
static volatile bool     g_rpcWarn   = false;
static volatile uint32_t g_rpcWarnUs = 0;
static volatile uint32_t g_rpcDrops  = 0;

struct TxRec { uint8_t len; uint8_t b[ipc::IPC_HEADER + TX_PAYLOAD_MAX + ipc::IPC_TRAILER]; };
static mbed::CircularBuffer<TxRec, 32> txRing;
static rtos::Thread txThread(osPriorityBelowNormal, 4096, nullptr, "rpctx");

static void ipcSend(uint8_t type, const uint8_t* payload, uint16_t len) {
    if (!rpcOK) return;
    if (len > TX_PAYLOAD_MAX) len = TX_PAYLOAD_MAX;
    TxRec r;
    r.b[0] = ipc::IPC_START;
    r.b[1] = type;
    r.b[2] = (uint8_t)(len & 0xFF);
    r.b[3] = (uint8_t)(len >> 8);
    if (len) memcpy(&r.b[ipc::IPC_HEADER], payload, len);
    r.b[ipc::IPC_HEADER + len] = ipc::checksum(r.b, len);
    r.len = (uint8_t)(ipc::IPC_HEADER + len + ipc::IPC_TRAILER);
    if (txRing.full()) { g_rpcDrops++; return; }   // ! drop and count, never block
    txRing.push(r);
}

static void txThreadFn() {
    TxRec r;
    while (true) {
        while (txRing.pop(r)) {
            uint32_t t0 = micros();
            RPC.write(r.b, r.len);
            uint32_t dt = micros() - t0;
            if (dt > RPC_WRITE_WARN_US) { g_rpcWarnUs = dt; g_rpcWarn = true; }
            if (r.b[1] != ipc::TYPE_DATA) {
                // USB mirror of log text lives HERE, off the flight loop
                Serial.write(&r.b[ipc::IPC_HEADER],
                             (size_t)r.len - ipc::IPC_HEADER - ipc::IPC_TRAILER);
                Serial.write((const uint8_t*)"\r\n", 2);
            }
        }
        ThisThread::sleep_for(1ms);
    }
}

static void ipcSendData(const SensorData& s) {
    // copy into the PACKED wire struct instead of sharing one struct: the wire
    // layout starts with a 1-byte state, so every float in it is misaligned -
    // using it directly in the flight loop would force unaligned/bytewise FP
    // access on every read. One ~90B copy per 10ms is the cheaper trade.
    PackedSensorData p;
    p.state = s.state; p.time = s.time; p.lat = s.lat; p.lon = s.lon;
    for (int i = 0; i < 3; ++i) {
        p.euler[i] = s.euler[i]; p.accel[i] = s.accel[i];
        p.gyro[i]  = s.gyro[i];  p.pos[i]   = s.pos[i];
    }
    p.altitude = s.altitude; p.pressure = s.pressure;
    for (int i = 0; i < 4; ++i) p.kalman[i] = s.kalman[i];
    p.gnssAlt = s.gnssAlt;
    p.health = s.health;
    ipcSend(ipc::TYPE_DATA, (const uint8_t*)&p, sizeof(p));
}

//~~~~~~~~~~~~~~~~~~~~~~~~~~~~~~~~~~~~~~~~~~~~~~~~~~~~~~~~~~~~~~~//
//~~~~~~~~~~~~~~~~~~~~~~~~ [7] Logging ~~~~~~~~~~~~~~~~~~~~~~~~~~//
//~~~~~~~~~~~~~~~~~~~~~~~~~~~~~~~~~~~~~~~~~~~~~~~~~~~~~~~~~~~~~~~//
// Tag protocol ([INIT]/[CAL]/[ZERO]/[TEST]/[STATE]/[BARO]/[SYS]/[WARN]/[ERROR])
// is defined in README 6.9.
// default = USB + XBEE + SD; pass ipc::TYPE_LOG_SD for bulk SD-only output.
// Every line is prefixed "[ms] " on the M7 MISSION clock - the same axis as the
// CSV time_ms column, so txt events and CSV rows line up with no conversion.
// During setup the prefix is the boot clock (Setup_Time still 0); the switch is
// marked by "[ZERO] mission clock start" (README 5).
// ! no Serial here: the USB mirror happens in txThread when the frame is sent,
//   so the flight loop performs ZERO I/O of any kind (RPC or USB)
static void logMsg(const char* s, uint8_t type = ipc::TYPE_LOG) {
    char b[112];
    int n = snprintf(b, sizeof(b), "[%lu] %s",
                     (unsigned long)(millis() - Setup_Time), s);
    if (n < 0) return;
    if ((size_t)n >= sizeof(b)) n = (int)sizeof(b) - 1;   // truncated, still sent
    ipcSend(type, (const uint8_t*)b, (uint16_t)n);
}

//### Deferred event log - state changes NOW, text AFTER runDecision ###
// ! logMsg rides on a BLOCKING RPC write. A warning produced while parsing or
//   health-checking must therefore never be SENT before the flight decision of
//   the same loop - only queued here and flushed after runDecision. Worst
//   same-loop burst is 4 events (gap warn + baro recovered + imu/gnss lost);
//   depth 6 leaves margin, overflow silently drops (README 6.7).
static char    g_evtQ[6][80];
static uint8_t g_evtCnt = 0;
static uint32_t g_evtDrops = 0;
static void logEvent(const char* s) {
    if (g_evtCnt < 6) {
        strncpy(g_evtQ[g_evtCnt], s, sizeof(g_evtQ[0]) - 1);
        g_evtQ[g_evtCnt][sizeof(g_evtQ[0]) - 1] = '\0';
        g_evtCnt++;
    } else g_evtDrops++;
}
static void flushEvents() {
    for (uint8_t i = 0; i < g_evtCnt; ++i) logMsg(g_evtQ[i]);
    g_evtCnt = 0;
}

//~~~~~~~~~~~~~~~~~~~~~~~~~~~~~~~~~~~~~~~~~~~~~~~~~~~~~~~~~~~~~~~//
//~~~ [8] Parsing (byte loops here, line parsing lives in parsers.h) ~//
//~~~~~~~~~~~~~~~~~~~~~~~~~~~~~~~~~~~~~~~~~~~~~~~~~~~~~~~~~~~~~~~//
void parseGNSS(SensorData &d) {
    static parsers::UbxPosllh ubx;
    while (GNSS.available()) {
        if (ubx.feed((uint8_t)GNSS.read())) {
            gnssLastMs = millis();   // checksum-valid frame = receiver alive
            if (ubx.hAccM <= GNSS_HACC_MAX_M &&
                fabsf(ubx.lat) <= 90.0f && fabsf(ubx.lon) <= 180.0f) {
                d.lat     = ubx.lat;   // ! hAcc gate stands in for the missing
                d.lon     = ubx.lon;   //   fix flag (README 6.3)
                d.gnssAlt = ubx.hMSLm; // log/recovery only, never control
            }
        }
    }
}
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
void loop() {
    uint32_t loopT0 = micros();   // worst-case work-time instrumentation
    parseGNSS(d);
    parseIMU(d);
    d.time = millis() - Setup_Time;

    if (parseBaro(d)) parseKalman(d);   // ! UKF at 50Hz, everything else 100Hz

    updateSensorHealth();
    runDecision(d);

    switch (flightState) {
        case FlightState::LAUNCH: d.state = 0xBB; break;
        case FlightState::DEPLOY: d.state = 0xBC; break;
        case FlightState::LANDED: d.state = 0xBD; break;
        default:                  d.state = 0xBA; break;
    }

    d.health = sensorFlags();
    ipcSendData(d);
    flushEvents();
    // ! the ONLY exit for deferred warnings - always after runDecision, and
    //   after the data frame so M4's record order stays data-then-text

    //### Baro cadence: arm once, then keep watching (post-decision zone) ###
    // ! the UKF hardcodes dt=0.02s, so a systematically different sensor rate
    //   scales every velocity estimate. vzCadenceOK starts false: vz stays
    //   disarmed until the first CADENCE_ARM_N clean intervals prove the rate,
    //   then every CADENCE_BLOCK_N intervals re-check it (a mid-flight slowdown
    //   raises the mean; phase jitter 10/30ms does not move it). Any failure is
    //   permanent for the flight - vzTrusted drops too, so the CSV note reads
    //   vz_off, not the transient vz_settle. Outliers are excluded upstream
    //   (single dropped samples are the per-sample gap check's job).
    static bool cadenceArmDone = false;
    if (!cadenceArmDone) {
        if (baroIvalCnt >= CADENCE_ARM_N) {
            cadenceArmDone = true;
            float mean = (float)baroIvalSum / (float)baroIvalCnt;
            baroIvalSum = 0; baroIvalCnt = 0;
            vzCadenceOK = (mean >= CADENCE_MEAN_LO_MS && mean <= CADENCE_MEAN_HI_MS);
            if (!vzCadenceOK) vzTrusted = false;
            char m[96];
            snprintf(m, sizeof(m), "[%s] Baro cadence: n=%u mean=%.2fms (UKF assumes 20.00) %s",
                     vzCadenceOK ? "ZERO" : "WARN", (unsigned)CADENCE_ARM_N, (double)mean,
                     vzCadenceOK ? "OK" : "-> vz deploy path disabled");
            logMsg(m);
        } else if (d.time > (float)CADENCE_DEADLINE_MS) {
            // never collected enough clean intervals - fail closed, but SAY so
            // (a boot-dead baro stays quiet: "Baro lost" already told the story)
            cadenceArmDone = true;
            if (baroAlive && vzTrusted) {
                vzTrusted = false;
                char m[96];
                snprintf(m, sizeof(m),
                         "[WARN] Baro cadence: insufficient clean samples (n=%lu) - vz deploy path disabled",
                         (unsigned long)baroIvalCnt);
                logMsg(m);
            }
        }
    } else if (baroIvalCnt >= CADENCE_BLOCK_N) {
        float mean = (float)baroIvalSum / (float)baroIvalCnt;
        baroIvalSum = 0; baroIvalCnt = 0;
        // ! reset is unconditional - inside the vzCadenceOK branch the counters
        //   would never reset again after a trip
        if (vzCadenceOK && (mean < CADENCE_MEAN_LO_MS || mean > CADENCE_MEAN_HI_MS)) {
            vzCadenceOK = false;
            vzTrusted   = false;
            vwVz.reset();   // scaled votes gathered before the trip are void
            logMsg("[WARN] vz deploy path disabled (baro cadence drift)");
        }
    }

    //### RPC link report (slow writes seen by txThread + ring/event drops) ###
    static uint32_t lastRpcLog = 0, dropsReported = 0, evtReported = 0;
    uint32_t dropsNow = g_rpcDrops;
    if ((g_rpcWarn || dropsNow != dropsReported || g_evtDrops != evtReported) &&
        millis() - lastRpcLog >= 5000) {
        lastRpcLog = millis();
        char m[96];
        snprintf(m, sizeof(m), "[WARN] RPC link: slow=%luus dropped=%lu evdrop=%lu",
                 (unsigned long)g_rpcWarnUs, (unsigned long)dropsNow,
                 (unsigned long)g_evtDrops);
        g_rpcWarn = false;
        dropsReported = dropsNow;
        evtReported = g_evtDrops;
        logMsg(m);
    }

    //### Loop timing report: worst work-time + skipped deadlines ###
    static uint32_t loopMaxUs = 0, dlSkips = 0, lastLoopLog = 0, skipsReported = 0;
    uint32_t work = micros() - loopT0;
    if (work > loopMaxUs) loopMaxUs = work;
    if ((loopMaxUs > 5000 || dlSkips != skipsReported) && millis() - lastLoopLog >= 10000) {
        lastLoopLog = millis();
        char m[80];
        snprintf(m, sizeof(m), "[WARN] loop max %luus, deadline skips=%lu",
                 (unsigned long)loopMaxUs, (unsigned long)dlSkips);
        loopMaxUs = 0;              // rolling max per report window
        skipsReported = dlSkips;
        logMsg(m);
    }

    //### Fixed 100Hz by absolute deadline; missed deadlines are skipped, ###
    //### never caught up, so the 10ms grid phase holds.                  ###
    static auto next_deadline = Kernel::Clock::now();
    next_deadline += milliseconds(LOOP_PERIOD_MS);
    const auto tick_now = Kernel::Clock::now();
    while (next_deadline < tick_now) {
        next_deadline += milliseconds(LOOP_PERIOD_MS);
        dlSkips++;
    }
    ThisThread::sleep_until(next_deadline);
}

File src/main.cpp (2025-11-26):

#include <Arduino.h>
#include <Servo.h>
#include <Wire.h>
#include <Adafruit_BMP3XX.h>
#include <Adafruit_Sensor.h>
#include "mbed.h"
#include "rtos.h"
#include <chrono>
#include "ukf.h"
#include "rtwtypes.h"

using namespace mbed;
using namespace rtos;
using namespace std::chrono;
kf Kalmanfilter;

//======= Data Structure=======
struct SensorData {
    uint8_t state=0xBA;//0xBA= Prelaunch, 0xBB= Launch, 0xBC= Deploy, 0xBD= Landed
    float time=0.0;
    float lat = 0.0;
    float lon = 0.0;
    float euler[3]= {0,0,0};
    float accel[3]= {0,0,0};
    float gyro[3]= {0,0,0};
    float pos[3]= {0,0,0};
    float altitude=0.0;
    float pressure = 0.0;
    float kalman[4]= {0,0,0,0};
};

struct __attribute__((packed)) PackedSensorData {
    uint8_t state=0xBA;
    float time=0.0;
    float lat=0.0;
    float lon=0.0;
    float euler[3]= {0,0,0};
    float accel[3]= {0,0,0};
    float gyro[3]= {0,0,0};
    float pos[3]= {0,0,0};
    float altitude=0.0;
    float pressure=0.0;
    float kalman[4]= {0,0,0,0};
};

//==== Sensor Mapping ==========
Adafruit_BMP3XX Barometer;
Servo           Parachute;
HardwareSerial& XBEE = Serial1;
UART            GNSS(PG_14, PG_9, NC, NC);
UART            IMU(PJ_8, PJ_9, NC, NC);

//======= Flight State ========
enum class  FlightState {CALIBRATION, PRELAUNCH, LAUNCH, DEPLOY, LANDED};
Mutex flightStateMutex;
FlightState flightState = FlightState::CALIBRATION;

//======= Parameter ===========
uint32_t        hold                    = 20;       // ms (1000/hold fps)
const float     launchThreshold         = 2;        // g
unsigned long   force_deploy_time       = 14000;    // ms
const float     fallingspeedThreshold   = -7;       // m/s
const float     tiltThreshold           = 45;       // degree



//======= variable ===========
uint32_t        Setup_Time              = 0; // ms
uint32_t        loop_start              = 0; // loop
uint32_t        loop_interval           = 0; // loop
float           basePressure            = 1013.0f;  // hPa

//=========== RTOS ================
Mail<SensorData, 4> xbeeMail;
Mail<SensorData, 4> decisionMail;
Thread              decisionThread;
Thread              xbeeThread;
SensorData          d{};

//=================================================
// Parsing tools
//=================================================
void parseGNSS(SensorData &d) {
  // 한 함수 안에 모든 로직(체크섬/토큰분리/좌표변환) 포함
  static char   nmeaBuf[128];
  static size_t nmeaPos = 0;

  // ---- 로컬 람다: 체크섬 ----
  auto checksumOK = [](const char* s)->bool {
    if (!s || s[0] != '$') return false;
    uint8_t cs = 0; 
    const char* p = s + 1;
    while (*p && *p != '*') cs ^= static_cast<uint8_t>(*p++);
    if (*p != '*') return false;
    auto hex = [](char c)->int{
      if ('0'<=c && c<='9') return c-'0';
      if ('A'<=c && c<='F') return 10 + (c-'A');
      if ('a'<=c && c<='f') return 10 + (c-'a');
      return -1;
    };
    if (!p[1] || !p[2]) return false;
    int hi = hex(p[1]), lo = hex(p[2]);
    if (hi<0 || lo<0) return false;
    return cs == static_cast<uint8_t>((hi<<4)|lo);
  };

  // ---- 로컬 람다: ',' 기준 토큰 분리 ----
  auto splitComma = [](char* line, char** fields, int maxF)->int {
    for (char* q=line; *q; ++q) if (*q=='\r' || *q=='\n') *q = '\0';
    int n = 0;
    char* p = line;
    if (*p=='$') ++p;
    fields[n++] = p;
    while (*p && n < maxF) {
      if (*p == ',') { *p = '\0'; fields[n++] = p + 1; }
      else if (*p == '*') { *p = '\0'; break; }
      ++p;
    }
    return n;
  };

  // ---- 로컬 람다: ddmm.mmmm -> degree ----
  auto toDeg = [](const char* v, const char* hemi, bool isLat, float& out)->bool {
    if (!v || !*v || !hemi || !*hemi) return false;
    double raw = strtod(v, nullptr);
    int degPart = static_cast<int>(floor(raw / 100.0));
    double minPart = raw - degPart * 100.0;
    double deg = degPart + (minPart / 60.0);
    char h = toupper(*hemi);
    if ((isLat && h=='S') || (!isLat && h=='W')) deg = -deg;
    if (isLat)  { if (deg < -90.0  || deg > 90.0)  return false; }
    else        { if (deg < -180.0 || deg > 180.0) return false; }
    out = static_cast<float>(deg);
    return true;
  };

  // ---- UART에서 한 줄 읽기 & 파싱 ----
  while (GNSS.available()) {
    char c = GNSS.read();
    //XBEE.write(0xAA);
    //XBEE.print(c);
    if (c == '\r') continue;

    if (c == '\n') {
      nmeaBuf[nmeaPos] = '\0';
      nmeaPos = 0;

      if (nmeaBuf[0] != '$') continue;
      if (!checksumOK(nmeaBuf)) continue;

      // 사본에서 토큰 분리
      char line[128];
      strncpy(line, nmeaBuf, sizeof(line));
      line[sizeof(line)-1] = '\0';

      char* f[24];
      int nf = splitComma(line, f, 24);
      if (nf < 6) continue;

      // ---- RMC: $GNRMC or $GPRMC ----
      if (!strcmp(f[0], "GNRMC") || !strcmp(f[0], "GPRMC")) {
        // $GNRMC, time, status(A/V), lat, NS, lon, EW, ...
        if (nf >= 7 && f[2] && f[2][0]=='A') {
          float lat, lon;
          bool ok1 = toDeg(f[3], f[4], true,  lat);
          bool ok2 = toDeg(f[5], f[6], false, lon);
          if (ok1) d.lat = lat;
          if (ok2) d.lon = lon;
        }
        continue;
      }

      // ---- GGA: $GNGGA or $GPGGA ----
      if (!strcmp(f[0], "GNGGA") || !strcmp(f[0], "GPGGA")) {
        // $GNGGA, time, lat, NS, lon, EW, fixQ, ...
        if (nf >= 6) {
          float lat, lon;
          bool ok1 = toDeg(f[2], f[3], true,  lat);
          bool ok2 = toDeg(f[4], f[5], false, lon);
          if (ok1) d.lat = lat;
          if (ok2) d.lon = lon;
        }
        continue;
      }

      // 다른 문장은 무시
      continue;
    }

    if (nmeaPos < sizeof(nmeaBuf) - 1) nmeaBuf[nmeaPos++] = c;
    else nmeaPos = 0; // 오버플로우 시 리셋
  }
}
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

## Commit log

2025-12-02 지상국 코드 추가
2026-05-05 fix 세훈 바보
2026-09-16 chore: checkpoint ground station before firmware migration
    [current_pos_box.stl, log_20260808_055137.csv, log_20260808_230923.csv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]
2026-09-16 fix: bound velocity fallback and decode SD replay health
    [main_m7.cpp]
